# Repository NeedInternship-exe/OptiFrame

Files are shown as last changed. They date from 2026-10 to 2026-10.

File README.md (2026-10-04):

# OptiFrame — des verres recyclés à la monture imprimée en 3D

Web app mobile (défi CodeML × Santé Numérique Sans Frontières) : on photographie un verre de lunettes
recyclé posé sur **une simple feuille blanche** (ou sur notre tapis imprimé, plus précis), l’app mesure son contour au dixième de millimètre et génère une
monture sur mesure **prête à imprimer en 3D**, même quand le verre gauche et le verre droit n’ont pas
la même forme.

**➡️ App : https://needinternship-exe.github.io/OptiFrame/** · aucun compte, aucune installation, fonctionne hors ligne après la 1re ouverture.

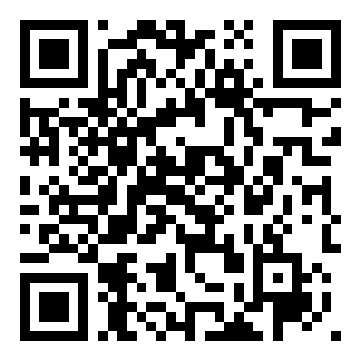
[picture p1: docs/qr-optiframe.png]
QR code de l’application


| Palier | Statut | Où |
|---|---|---|
| 1 · Mesurer (photo → repères → vue de dessus → contour → A, B, périmètre + image de contrôle) | ✅ | onglet **Mesurer** |
| 2 · IA (U-Net entraîné sur données synthétiques, exécuté dans le navigateur) | ✅ | `ml/`, onglet **Pas à pas** |
| 3 · Monture paramétrique (2 contours différents, pont, tenons) + aperçu 3D + STL | ✅ | onglet **Monture** |
| 4 · Valider (superposition contour/rainure, écart entre prises, pied à coulisse) | ✅ | onglet **Valider** |

---

## 1. Tester en 30 secondes

1. Scanner le QR code (Chrome Android ou Safari iOS).
2. Rien sous la main ? **« Essayer avec une photo d’exemple »** lance tout le traitement sur une photo de démonstration (synthétique).
3. **Sans rien imprimer** : une feuille blanche Lettre ou A4 sur une table foncée, les verres dessus, **Photographier** (les 4 coins de la feuille visibles).
4. Plus précis : le tapis imprimé ([Lettre](public/mat/optiframe-mat-lettre.pdf) ou [A4](public/mat/optiframe-mat-A4.pdf)), idéalement posé sur une boîte lumineuse.
5. Onglet **Monture** → **Télécharger monture.stl**. Onglet **Mesurer** → **Contours SVG 1:1** (à imprimer pour poser le verre sur son tracé).

## 2. Dispositif de capture (remontable en moins d’une minute)

**Option 1 : une feuille blanche, rien à imprimer.** Une feuille Lettre ou A4 a une taille connue. Ses 4 coins suffisent pour l’échelle et la perspective (la feuille A4 est citée dans les consignes comme objet de référence).
- Posez la feuille à plat sur une table plus foncée que le papier, puis les verres face bombée vers le haut, à plus de 1 cm des bords. Le verre de gauche est le verre droit (OD).
- L’app trouve la feuille, puis ajuste une droite sur chaque bord, d’abord avec une recherche large qui récupère un coin assombri par une ombre, puis au sous-pixel en pleine résolution.
- Le format (Lettre ou A4) et l’orientation sont choisis automatiquement par **cohérence géométrique** : avec le bon format, l’homographie correspond à une vraie caméra (axes orthogonaux et de même norme).
- Le haut de la photo définit le haut des verres : on tient le téléphone droit.

**Option 2 : le tapis imprimé, plus précis et robuste.**

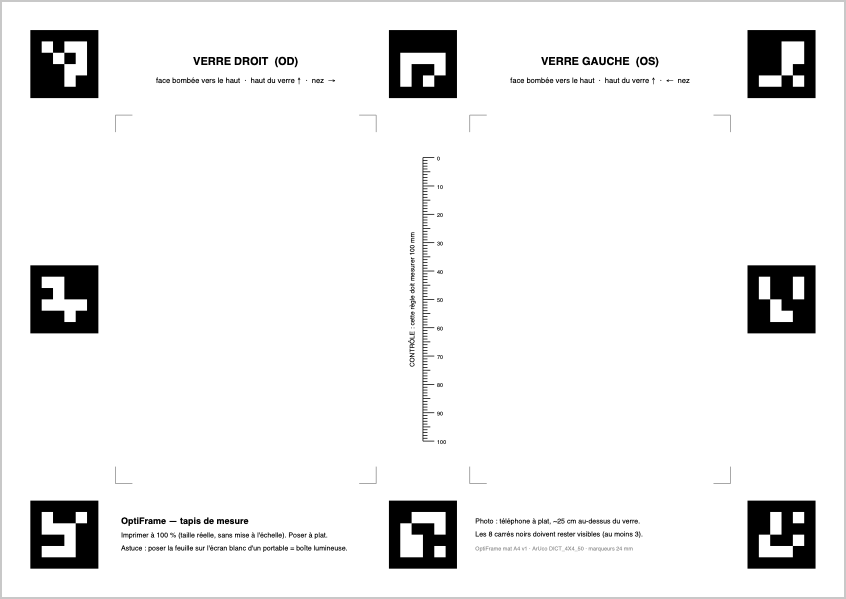
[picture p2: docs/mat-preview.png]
tapis


- **Une feuille imprimée à 100 %**, [Lettre](public/mat/optiframe-mat-lettre.pdf) ou [A4](public/mat/optiframe-mat-A4.pdf). Le même tapis tient sur les deux papiers, car il est dessiné sur leur intersection (279,4 × 210 mm). Il porte 8 marqueurs ArUco (`DICT_4X4_50`, 24 mm) autour de deux zones :
  **OD** (verre droit, à gauche comme sur des lunettes vues de face) et **OS** (verre gauche). Une **règle de 100 mm** permet de vérifier l’échelle d’impression ;
  si l’imprimante a réduit la page, on saisit la longueur réelle dans *Aide → Réglages* et toutes les mesures sont corrigées.
- **Boîte lumineuse (recommandée)** : poser le tapis sur l’écran d’un portable affichant du blanc (bouton *Boîte lumineuse* dans l’app). Le papier devient translucide et le bord du verre ressort en noir très net.
- Au moins 3 repères suffisent : on peut cadrer les deux zones à la fois ou une seule, de plus près.

**Lunettes montées (mode « Lunettes montées »).** Pour mesurer les verres d’une paire complète (par exemple celle du jury) sans les démonter :
- poser les lunettes **face avant contre la feuille**, branches ouvertes vers le haut. Rien ne doit passer devant les verres : une branche repliée sur un verre cache sa forme ;
- l’IA, entraînée aussi sur des montures synthétiques (écaille, couleur, noir, métal fin, acétate transparent), détoure l’**ouverture de chaque cercle**. Le recalage cherche alors le bord « verre clair → cercle sombre » ;
- la photo voit l’arrière : l’app inverse gauche et droite et remet chaque forme en vue de face. Elle corrige la parallaxe pour un bord à environ 3,5 mm du papier (l’épaisseur du cercle), puis ajoute la **profondeur de rainure** (0,5 mm par défaut, réglable), c’est-à-dire la partie du verre cachée dans le cercle.

**Dans les deux cas**, le verre est posé face bombée vers le haut : son bord touche le papier, il est donc dans le plan de référence.
Le bord reste un peu au-dessus du papier : l’app corrige cette **parallaxe** à partir de la position de la caméra retrouvée par l’homographie.

## 3. Comment ça marche

Tout le traitement tourne **dans le navigateur** (Web Workers, WebAssembly) : pas de serveur, les photos ne quittent pas le téléphone.

```
photo ─► 1. Référence ──► 2. Homographie ─► 3. Vue de dessus ─► 4. Segmentation IA ─► 5. Contour sub-pixel ─► mesures
          ArUco (tapis)       mm ↔ px            6 px/mm (contrôle)   U-Net, ONNX Runtime    recalage sur la photo     A, B, périmètre,
          ou 4 coins de       (32 ou 4 coins)    3 px/mm (IA)         Web (wasm)             d'origine + parallaxe     ED, SVG 1:1
          la feuille
                                                                                                    │
                                                    monture.stl ◄─ 6. CAO paramétrique (manifold-3d) ◄┘
```

1. **Référence** — sans tapis, la feuille blanche est détectée et ses bords ajustés (voir plus haut). Avec le tapis, OpenCV.js détecte les marqueurs sur une copie réduite (rapide), puis chaque coin est **ré-estimé en pleine résolution
   en ajustant une droite sur les 4 bords de chaque marqueur** (~30 profils de gradient sub-pixel par bord, rejet des aberrants), puis intersection.
   Utiliser des bords entiers plutôt que des pixels de coin rend l’homographie bien plus stable. La largeur de transition des bords donne une **mesure de netteté en mm**.
2. **Homographie** — jusqu’à 32 correspondances mm ↔ px, RANSAC puis moindres carrés. Indicateurs affichés : erreur de reprojection (typiquement < 0,02 mm), résolution (px/mm), inclinaison et hauteur de la caméra.
3. **Redressement** — chaque zone visible est ré-échantillonnée en vue de dessus (anti-crénelage par réduction préalable), à 6 px/mm pour l’image de contrôle et 3 px/mm pour l’IA.
4. **Segmentation** — un U-Net (0,5 M paramètres) donne une carte de probabilité « verre ». Repli automatique sur une segmentation classique (normalisation de l’éclairage + Canny + remplissage) si le modèle n’est pas chargé.
5. **Contour** — iso-ligne 0,5 sub-pixel de la carte, puis **recalage sur le bord réel dans la photo d’origine** : chaque point est déplacé le long de sa normale vers le pic de gradient « bord sombre → papier », échantillonné directement dans la photo pleine résolution via l’homographie (aucune perte de ré-échantillonnage). Filtre médian + lissage de Fourier (60 harmoniques), puis correction de parallaxe, d’échelle d’impression et d’un biais calibrable.
6. **Mesures (système boxing, ISO 8624)** — A, B, périmètre, diamètre effectif. Un verre posé de travers est redressé (rectangle d’encadrement minimal, ±8°).

## 4. Données et IA

> Détails, commandes et courbes : [`ml/README.md`](ml/README.md).

**Le problème** : un verre est transparent ; reflets, ombres, traitements anti-reflet colorés et bords peu contrastés font échouer le seuillage classique.
Aucun jeu de données n’existe pour « un verre de lunettes posé sur un tapis vu de dessus ». **Nous l’avons fabriqué.**

**Idée clé : entraîner dans le domaine redressé.** L’app redresse toujours la zone du tapis en vue de dessus à 3 px/mm avant la segmentation.
Le modèle ne voit donc jamais de perspective ni d’échelle variable : seulement du papier, les marques imprimées du tapis et un verre.
Ce domaine très contraint est **simulable de façon réaliste** — chaque image d’entraînement est rendue à partir du vrai fichier du tapis.

**Générateur synthétique** ([`ml/lenssynth.py`](ml/lenssynth.py), [`ml/dataset.py`](ml/dataset.py)) — chaque échantillon est entièrement déterminé par sa graine (jeu reproductible, illimité, 60 ms/image) :
- **formes** : superellipses, séries de Fourier, aviateur, œil-de-chat, pantos, rond, hexagonal/octogonal (A de 33 à 64 mm) ;
- **optique** : réfraction (minification/grossissement du papier et des marques), transmission et teintes (verres clairs, anti-reflet, solaires) ;
- **le bord vu de dessus** : bande sombre de largeur et contraste variables, reflets brillants, **segments où le bord disparaît presque** ;
- **pièges** : « anneau myopique » à l’intérieur des verres épais, ombre décalée du bord, ombre du téléphone, reflets de fenêtre et du téléphone, voiles colorés d’anti-reflet, points d’encre du frontofocomètre, trous de perçage, poussières ;
- **éclairage et caméra** : mode boîte lumineuse / lumière ambiante, gradients, flou, bruit, gamma, balance des blancs, JPEG.

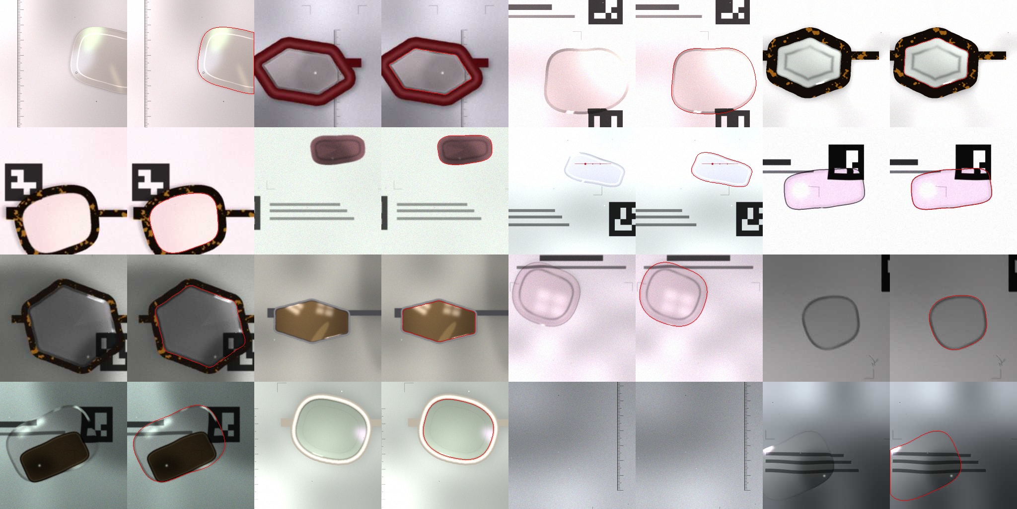
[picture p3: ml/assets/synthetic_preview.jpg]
échantillons synthétiques


**Modèle** ([`ml/train.py`](ml/train.py)) — U-Net à convolutions 3×3 (12→96 canaux, 5 niveaux), 516 k paramètres, ~2 GMAC par zone, entièrement convolutif.
Perte : entropie croisée pondérée ×5 près du bord + Dice, étiquettes douces anti-crénelées (le bord à 0,5 tombe exactement sur le vrai contour).
AdamW + OneCycle, 6 000 itérations puis 5 000 de reprise à taux décroissant × 16 images (176 000 images vues), IoU de validation 0,968, GPU Apple M4 (MPS), ~2 h. Export ONNX (2 Mo), exécution par ONNX Runtime Web (wasm SIMD) : ~0,3 s par zone sur un M4.

**Évaluation de bout en bout** ([`bench/run.ts`](bench/run.ts)) — le *même code TypeScript que l’app* est exécuté sous Node sur 24 photos de téléphone simulées
([`ml/make_photos.py`](ml/make_photos.py) : 36 verres, inclinaison 0–28°, téléphone tourné, table autour du tapis, défocalisation, bruit, JPEG), dont le contour exact est connu (tapis : 24 photos, 34 verres ; feuille blanche : 24 photos, 35 verres) :

| Référence · méthode | Verres trouvés | Erreur moy. A et B | ≤ 1 mm | lumière ambiante | boîte lumineuse |
|---|---|---|---|---|---|
| Tapis · classique (sans IA) | 29 / 34 | 1,86 mm | 68 % | 2,24 mm | 0,06 mm |
| Tapis · IA sans affinage | 34 / 34 | 0,21 mm | 100 % | 0,21 mm | 0,22 mm |
| **Tapis · IA + affinage** | **34 / 34** | **0,16 mm** | **100 %** | 0,19 mm | 0,07 mm |
| **Feuille Lettre · IA + affinage** | **23 / 23** | **0,17 mm** | 96 % | 0,17 mm | — |
| **Feuille A4 · IA + affinage** | 11 / 12 | **0,16 mm** | 92 % | 0,16 mm | — |

Résolution caméra navigateur (1920 × 1440, tapis) : 0,29 mm, 93 % ≤ 1 mm. Photos de test reproductibles : `python make_photos.py [--sheet letter|a4] [--res 1920x1440]`.

**Vérité terrain réelle** : protocole pour vos propres verres — saisir les cotes au pied à coulisse (système boxing) dans *Valider*, l’app calcule l’erreur, exporte un CSV et peut **calibrer automatiquement le biais du contour** (*Aide → Calibrer*).

**Sources et licences** : aucune donnée personnelle, aucune image tierce — 100 % des images d’entraînement sont générées par nos scripts (licence MIT du dépôt).
Pas de modèle pré-entraîné (Segment Anything a été envisagé, mais ses ~40 Mo et plusieurs secondes par image sur téléphone ne tiennent pas le budget de 30 s et le mode hors ligne).

## 5. La monture

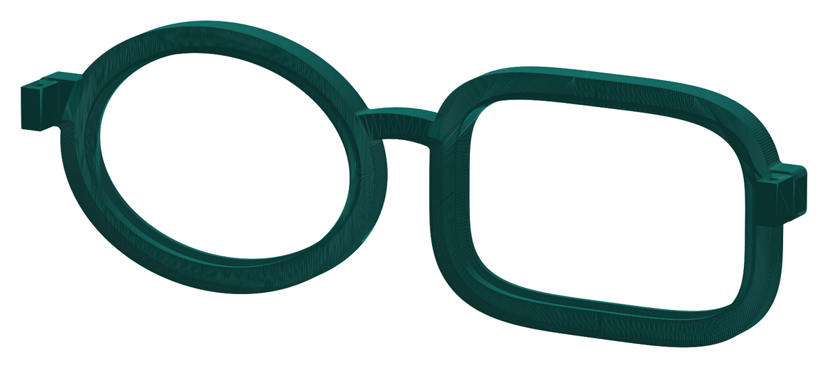
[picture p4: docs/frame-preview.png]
monture


Générée par [`src/frame/frame.ts`](src/frame/frame.ts) avec **manifold-3d**, une bibliothèque qui garantit un maillage fermé (STL valide). Le module est vérifié par un test automatique : `npm run test`.

- **Chaque cercle épouse son verre** : le contour mesuré est décalé vers l’extérieur (largeur du cercle, 4 mm par défaut). Les deux verres peuvent avoir des formes différentes. S’il en manque un, l’autre est utilisé en miroir.
- **Rainure en V à 45°** pour le clipsage, avec un jeu de 0,2 mm au fond (réglable de 0 à 0,5 mm). Une lèvre avant de 0,8 mm retient le verre et une lèvre arrière de 0,4 mm le clipse. Les parois à 45° **s’impriment sans supports**, face avant sur le plateau.
- **Pont** en arche réglable (18 mm par défaut, norme DBL), avec les centres de boxing alignés sur la ligne de référence.
- **Tenons des branches** avec un bloc de charnière. Le trou de l’axe est **en goutte d’eau** pour s’imprimer sans support ; un morceau de filament de 1,75 mm sert d’axe.
- **Contrôles sur le maillage final** : arêtes libres, genre topologique, volume, masse. L’app découpe la monture générée au niveau de la rainure et mesure l’écart réel avec le contour du verre (onglet Valider). Valeur obtenue : 0,200 mm pour une consigne de 0,2.

## 6. Exigences du format

| Exigence | Réalisation |
|---|---|
| HTTPS + QR code | GitHub Pages ([workflow](.github/workflows/deploy.yml)) ; QR code dans l’app (*Aide*) et ci-dessus |
| Aucune installation, compte ou clé | Site statique, PWA installable en option |
| Mobile d’abord, utilisable à une main | Barre d’onglets en bas, gros boutons, testé à 375 px de large |
| Caméra intégrée + import en repli | `getUserMedia` avec guidage en direct (repères détectés, zone visible, inclinaison), `ImageCapture.takePhoto()` en pleine résolution sur Android, sinon import de fichier |
| Traitement dans le navigateur | OpenCV.js + ONNX Runtime Web dans un Worker, CAO dans un second Worker, cache hors ligne (service worker) |
| Moins de 30 s par paire | ~1,6 à 2 s pour une photo de la paire sur un M4 |
| Export du contour en SVG 1:1 | `contours-1-1.svg` (A4, règle de contrôle de 50 mm) |
| Messages clairs | Tapis absent, repères insuffisants, photo floue, feuille non plane, photo trop inclinée, zone hors cadre, verre absent, verre au bord, contour incertain : chaque message est accompagné d’un conseil |

## 7. Limites connues (honnêtement)

- **Modèle entraîné uniquement sur des images synthétiques.** Les photos réelles peuvent présenter des effets non simulés. Le banc d’essai mesure la précision sur des photos synthétiques : il faut **valider sur de vrais verres au pied à coulisse** (protocole intégré à l’app) et compléter avec des photos réelles annotées (voir `ml/README.md`, « capture appariée »).
- **L’échelle dépend de la référence.** Avec le tapis, contrôler la règle de 100 mm (correction possible dans l’app). Avec une feuille blanche, la précision dépend de la coupe du papier (±0,5 mm sur 280 mm, soit environ 0,1 mm sur un verre) et de sa planéité. La feuille doit contraster avec la table.
- **Hauteur du bord pour la parallaxe** : la valeur par défaut est de 1 mm. Une erreur de 1 mm sur cette hauteur produit environ 0,1 à 0,2 mm d’erreur sur A.
- **Orientation du verre** : A et B dépendent de l’orientation horizontale du verre. Il faut poser le verre droit ; l’app ne corrige que ±8°.
- **Lunettes montées** : le contour d’un verre monté est estimé à partir de l’ouverture du cercle plus une profondeur de rainure typique (0,5 mm). C’est moins précis qu’un verre démonté, car la profondeur réelle varie de 0,3 à 1 mm selon la monture. La paire doit être posée face avant contre la feuille, branches ouvertes.
- **Monture** : les branches ne sont pas générées, seulement les tenons. Le clipsage dépend du matériau : en PLA rigide, réduire la lèvre arrière ou passer en PETG.
- **Sans IA** (modèle non chargé), la segmentation classique n’est fiable qu’avec la boîte lumineuse.

## 8. Lancer en local

```bash
npm install
npm run dev          # http://localhost:5173 (caméra : utiliser l'import de fichier, ou HTTPS)
npm run test         # génère une monture test et vérifie maillage fermé + rainure
npm run bench        # précision de bout en bout sur bench/photos (après ml/make_photos.py)
npm run build        # site statique dans dist/
```

Partie IA (Python 3.11+) :

```bash
cd ml && python -m venv .venv && .venv/bin/pip install -r requirements.txt
.venv/bin/python gen_mat.py                 # tapis PDF/SVG + rendus raster
.venv/bin/python dataset.py 16              # aperçu des données synthétiques
.venv/bin/python train.py --out runs/v1     # entraînement (MPS / CUDA / CPU)
.venv/bin/python export_onnx.py runs/v1/best.pt ../public/models/lens_seg.onnx
.venv/bin/python make_photos.py --n 24 --out ../bench/photos
```

## 9. Structure

```
src/core/      géométrie, homographie et pose caméra, mesures boxing, fusion de prises
src/vision/    pipeline (ArUco, redressement, segmentation, contour, affinage), worker, messages
src/frame/     CAO de la monture (manifold-3d), export STL, worker
src/ui/        interface Preact (caméra, onglets), dessins de contrôle
src/export/    SVG 1:1
ml/            tapis, générateur synthétique, entraînement, export ONNX, photos de test
bench/         banc d'essai de bout en bout (Node) et test de la monture
shared/        géométrie du tapis (partagée par Python et TypeScript)
```

## 10. Licences et outils

- Code du projet : **MIT**. Données d’entraînement : générées par nos scripts (MIT).
- [OpenCV.js](https://opencv.org) 4.9 (Apache 2.0) · [ONNX Runtime Web](https://onnxruntime.ai) (MIT) · [manifold-3d](https://github.com/elalish/manifold) (Apache 2.0) · [three.js](https://threejs.org) (MIT) · [Preact](https://preactjs.com) (MIT) · [qrcode](https://github.com/soldair/node-qrcode) (MIT) · [Vite](https://vite.dev) + vite-plugin-pwa (MIT).
- Entraînement : [PyTorch](https://pytorch.org) (BSD-3), opencv-python (Apache 2.0 / MIT), NumPy (BSD), ReportLab (BSD) pour le PDF du tapis.
- **Outils d’IA utilisés** : Claude Code (Anthropic, modèle Claude Opus) comme assistant de programmation pour l’architecture, le code, le générateur de données et la rédaction. Toutes les mesures citées proviennent des scripts du dépôt et sont reproductibles.

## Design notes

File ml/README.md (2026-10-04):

# Dossier « données et IA »

Objectif : isoler un verre de lunettes **transparent** dans une photo de téléphone, de façon assez fiable pour mesurer
sa largeur A et sa hauteur B à moins de 1 mm, malgré les reflets, les ombres et un bord souvent à peine visible.

## 1. Pourquoi des données synthétiques ?

Aucun jeu public ne montre « un verre de lunettes démonté, posé à plat, vu de dessus ». Les jeux d’objets transparents
(Trans10K, ClearGrasp…) montrent des verres à boire et des bouteilles, en perspective, avec des licences souvent non commerciales.
Ils ne correspondent ni au domaine ni à la précision voulue (sub-millimétrique).

**Le domaine redressé.** L’app commence par repérer les marqueurs ArUco du tapis, puis redresse chaque zone en vue de
dessus à 3 px/mm. Le réseau ne voit donc jamais de perspective ni d’échelle variable : seulement le papier, les marques
imprimées du tapis (coins, règle, textes, bords de marqueurs) et un verre. On peut simuler ce domaine très fidèlement, car on
part du **fichier exact du tapis** ([`gen_mat.py`](gen_mat.py) produit à la fois le PDF imprimé et les rendus utilisés pour l’entraînement).

## 2. Le générateur ([`lenssynth.py`](lenssynth.py), [`dataset.py`](dataset.py))

Chaque échantillon 256 × 256 px (85 × 85 mm) est rendu à 6 px/mm puis réduit à 3 px/mm (étiquettes douces anti-crénelées).
**Une graine entière détermine entièrement une image** : le jeu est illimité, reproductible, et ne contient aucune donnée personnelle.

| Famille | Ce qui est simulé (tirages aléatoires) |
|---|---|
| Formes | superellipse (p 2–5,5), Fourier, aviateur, œil-de-chat, pantos, rond, hexagone/octogone arrondi ; A 33–64 mm, B/A 0,48–1 ; rotation ±25°, miroir |
| Papier et lumière | teinte du papier, encre 4–25 % de gris, gradients et champ d’éclairage, vignettage, texture du papier, **ombre du téléphone** (35 %), **mode boîte lumineuse** (35 %) |
| Optique du verre | réfraction (grandissement 0,82–1,18 et distorsion lisse), transmission 85–99,5 %, **verres solaires teintés** (10 %) |
| Bord vu de dessus | bande sombre de 0,25 à 2,6 mm, contraste variable le long du contour, profils uniforme, dégradé ou ligne ; **segments où le bord disparaît** (30 %) ; liseré brillant interne ; reflets ponctuels |
| Pièges | **anneau myopique** interne (35 %), **ombre décalée du bord** (40 % en lumière ambiante), reflets en taches, de fenêtre ou du téléphone (sombre avec un point brillant), voile coloré d’anti-reflet (vert, violet, bleu, or), points et traits d’encre du frontofocomètre (25 %), trous de perçage (6 %), poussières, cheveux |
| Composition | 1 verre (86 %), 2 verres dont un partiellement hors champ (8 %), aucun verre (6 %, apprend à ne rien détecter) ; erreur d’échelle résiduelle ±6 % |
| Caméra | flou gaussien et de bougé, bruit dépendant du signal, gamma 0,8–1,25, balance des blancs, JPEG q45–95 |

aperçu

*Aperçu (`python dataset.py 16`) : image rendue à gauche, contour de vérité terrain en rouge à droite.*

## 3. Le modèle ([`train.py`](train.py))

- **U-Net à convolutions 3×3** : canaux 12, 24, 32, 48, 64, 96, 5 sous-échantillonnages, décodeur avec connexions de saut et suréchantillonnage bilinéaire, 516 k paramètres, ~2 GMAC pour une zone de 416 × 288 px.
- **Pourquoi des convolutions classiques et pas « depthwise »** : une première version MobileNet-like (280 k paramètres) prenait 557 ms par itération sur le GPU Apple (MPS), contre 225 ms pour cette version. ONNX Runtime Web exécute aussi très bien les convolutions denses en wasm SIMD.
- **Entièrement convolutif** : entraîné sur des recadrages 256 × 256, appliqué tel quel à une zone complète de 96 × 134 mm.
- La normalisation est intégrée au graphe : l’app envoie du RGB dans [0, 1].

**Entraînement** : perte = entropie croisée pondérée ×5 à moins de 1,5 mm du bord + 0,5 × Dice. AdamW (lr 2e-3, wd 1e-4), OneCycle,
6 000 itérations puis reprise de 5 000 itérations (lr 1e-3 décroissant) × 16 images, flux infini, validation sur 512 images fixes (graines 10 000 000+).
Matériel : Apple M4 (MPS), environ 2 h. Données générées en parallèle par 9 processus.

**Export** ([`export_onnx.py`](export_onnx.py)) : ONNX opset 17, hauteur et largeur dynamiques, 2 Mo. Écart maximal PyTorch ↔ onnxruntime : 7·10⁻⁶.
**Inférence** : ONNX Runtime Web (wasm), ~0,25 à 0,3 s par zone sur un M4 (mono-fil). Le modèle et le moteur sont mis en cache pour le mode hors ligne.

## 4. IA + géométrie : le contour final

Le réseau donne une carte de probabilité robuste mais à 0,33 mm/px. Pour atteindre la précision visée :
1. **iso-ligne 0,5 sub-pixel** de la carte : les étiquettes douces placent le 0,5 sur le vrai bord ;
2. **recalage sur la photo d’origine** : le long de chaque normale, on échantillonne la photo pleine résolution (via l’homographie, sans ré-échantillonnage) et on se cale sur le pic de gradient « bord sombre → papier » le plus proche (pondération gaussienne de 0,45 mm autour du contour IA, filtre médian, lissage) ;
3. corrections physiques : parallaxe du bord (hauteur caméra estimée), échelle d’impression, biais calibré.

L’IA apporte la **robustesse** (savoir où est le verre malgré les pièges), la géométrie apporte la **précision** (sub-pixel sur l’image native).

## 5. Évaluation

**Validation segmentation** (512 images synthétiques) : voir `runs/v1/log.json` (IoU, erreur A/B au pixel près).

**Bout en bout** ([`../bench/run.ts`](../bench/run.ts)) : le code TypeScript de l’app est exécuté sous Node sur 24 photos de téléphone
simulées ([`make_photos.py`](make_photos.py)). Ces photos comptent 36 verres, des inclinaisons de 0 à 28°, un téléphone tourné, la table
visible autour du tapis, de la défocalisation, du bruit et de la compression JPEG. A et B sont mesurés par la même procédure sur le contour trouvé et sur le contour vrai.

| Référence · méthode | Verres trouvés | Erreur moy. A et B | ≤ 1 mm | lumière ambiante | boîte lumineuse |
|---|---|---|---|---|---|
| Tapis · classique (sans IA) | 29 / 34 | 1,86 mm | 68 % | 2,24 mm | 0,06 mm |
| Tapis · IA sans affinage | 34 / 34 | 0,21 mm | 100 % | 0,21 mm | 0,22 mm |
| **Tapis · IA + affinage** | **34 / 34** | **0,16 mm** | **100 %** | 0,19 mm | 0,07 mm |
| **Feuille Lettre · IA + affinage** | **23 / 23** | **0,17 mm** | 96 % | 0,17 mm | — |
| **Feuille A4 · IA + affinage** | 11 / 12 | **0,16 mm** | 92 % | 0,16 mm | — |

Résolution caméra navigateur (1920 × 1440, tapis) : 0,29 mm, 93 % ≤ 1 mm. Photos de test reproductibles : `python make_photos.py [--sheet letter|a4] [--res 1920x1440]`.

## 6. Passer aux vraies photos : la « capture appariée »

La limite principale est l’écart entre synthétique et réel. Pour annoter de vraies photos difficiles **sans annotation manuelle** :
1. poser un verre sur le tapis, sur la **boîte lumineuse** : le bord est noir et net, la segmentation (même classique) est quasi parfaite ;
2. **sans bouger le verre**, éteindre l’écran et reprendre des photos en lumière de la pièce, avec reflets, sous un autre angle ;
3. comme toutes les photos sont redressées dans les coordonnées du tapis (en mm), **le masque de la photo facile s’applique exactement aux photos difficiles**.

On obtient en quelques minutes des dizaines d’exemples réels annotés, prêts pour affiner le modèle (`train.py --resume runs/v1/best.pt`, avec un mélange d’images réelles et synthétiques).
Les photos de l’évaluation finale ne sont jamais utilisées pour l’entraînement.

## 7. Licences

- Images d’entraînement : 100 % générées par nos scripts (MIT). Aucune image de visage, de nom ni d’ordonnance.
- Pas de poids pré-entraînés : le modèle est entraîné de zéro.
- Outils : PyTorch (BSD-3), OpenCV (Apache 2.0), NumPy (BSD), ONNX / onnxruntime (Apache 2.0 / MIT), ReportLab (BSD), Matplotlib (PSF).

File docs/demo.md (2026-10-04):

# Démo OptiFrame : 5 minutes + 2 minutes de questions

## Matériel (à vérifier avant de passer)
- 2 tapis A4 imprimés à 100 % : contrôler la règle de 100 mm au réglet, garder un tapis de rechange.
- Un portable ou une tablette avec l’app ouverte en mode **Boîte lumineuse** (Aide → Boîte lumineuse), luminosité au maximum.
- Un téléphone chargé avec l’app déjà ouverte une fois : le moteur est en cache, ce qui permet de fonctionner sans réseau.
- Le QR code affiché (README ou Aide → Partager), une monture imprimée si possible, la vidéo de secours sur le téléphone.

## Déroulé

| Temps | Action | Ce qu’on dit |
|---|---|---|
| 0:00 | QR code à l’écran, le jury scanne | « Aucune installation, aucun compte. Tout tourne dans le navigateur, hors ligne : pensé pour les zones sans opticien. » |
| 0:30 | Poser le tapis sur la boîte lumineuse, les 2 verres du jury face bombée vers le haut | « Dispositif en 30 secondes : une feuille A4, 8 repères ArUco, et l’écran d’un portable comme boîte lumineuse. » |
| 1:00 | **Photographier** : le guidage passe au vert (« Prêt · 8 repères ») | « Une seule photo pour les deux verres. » |
| 1:20 | Résultat : image de contrôle, A, B, périmètre | Lire A et B à voix haute, le jury compare avec son pied à coulisse. |
| 1:50 | **Pas à pas** : repères → vue redressée → carte de l’IA → contour affiné | « Affinage sub-pixel des repères, homographie à 0,01 mm de reprojection. L’IA trouve le verre malgré les reflets, puis on recale le contour sur la photo d’origine en pleine résolution. » |
| 2:40 | **Monture** : aperçu 3D, régler le pont (18 mm), **Télécharger monture.stl** | « Deux verres de formes différentes, deux cercles différents. Rainure en V à 45° qui s’imprime sans supports, jeu de 0,2 mm, tenons avec charnière. » |
| 3:30 | **Valider** : superposition verre/rainure (0,20 mm mesuré sur le maillage), reprendre une photo pour montrer ΔA/ΔB | « On contrôle la cohérence sur le maillage réel et entre deux prises. » |
| 4:10 | Données et IA (README) | « Aucun jeu de données n’existait : générateur synthétique dans le domaine redressé, 176 000 images. Sur photos simulées, l’erreur passe de 1,9 mm à 0,16 mm avec l’IA. Et la *capture appariée* permet d’annoter automatiquement de vraies photos. » |
| 4:40 | Limites (honnêtement) | « Modèle entraîné sur du synthétique, validé sur nos verres au pied à coulisse ; verres démontés uniquement ; les branches ne sont pas générées. » |

## Questions probables
- **Pourquoi pas Segment Anything ?** ~40 Mo et plusieurs secondes par image sur téléphone, sans mode hors ligne. Notre U-Net pèse 2 Mo et passe en environ 0,3 s.
- **D’où vient la précision ?** Repères affinés sur leurs bords, homographie sur 32 coins, contour recalé sur la photo native, correction de parallaxe, échelle d’impression contrôlée.
- **Et si l’imprimante réduit la page ?** On mesure la règle de 100 mm et on saisit la valeur : toutes les mesures sont corrigées, même les anciennes.
- **Le verre se clipse-t-il ?** Lèvre avant de 0,8 mm, lèvre arrière de 0,4 mm, jeu de 0,2 mm, tout est réglable. En PLA, on peut chauffer légèrement ; le PETG est plus souple.

## Plan B
- Pas de réseau : l’app est en cache (l’ouvrir une fois avant).
- Caméra refusée : bouton **Importer** (photo prise avec l’appareil photo natif).
- Rien ne marche : **Essayer avec une photo d’exemple**, puis la vidéo de secours.

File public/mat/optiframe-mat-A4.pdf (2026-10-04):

## VERRE DROIT (OD)

face bombée vers le haut · haut du verre ↑ · nez →

## VERRE GAUCHE (OS)

face bombée vers le haut · haut du verre ↑ · ← nez

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
CONTRÔLE : cette règle doit mesurer 100 mm

## OptiFrame — tapis de mesure

Imprimer à 100 % (taille réelle, sans mise à l'échelle). Poser à plat. Astuce : poser la feuille sur l'écran blanc d'un portable = boîte lumineuse.

Photo : téléphone à plat, ~25 cm au-dessus du verre. Les 8 carrés noirs doivent rester visibles (au moins 3).

OptiFrame mat v2 (Lettre/A4) · ArUco DICT_4X4_50 · marqueurs 24 mm

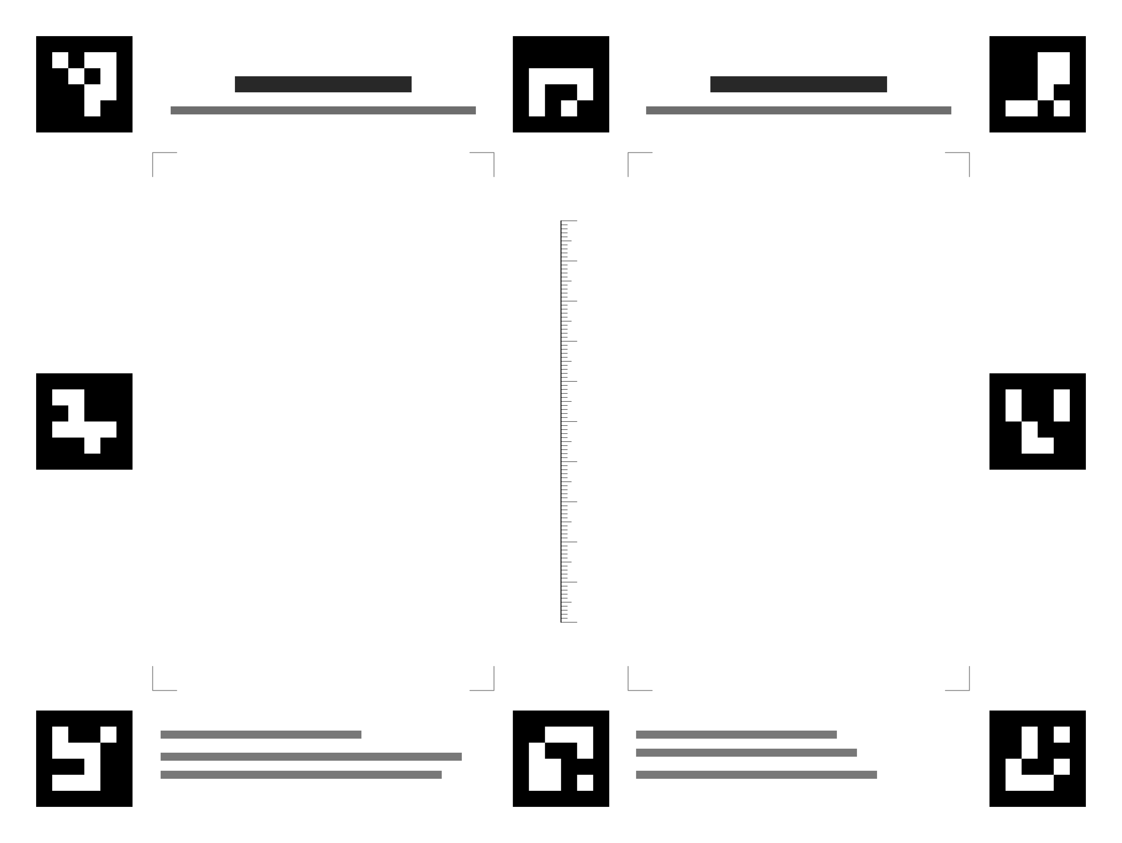
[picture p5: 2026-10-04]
ml/assets/mat_12ppm.png

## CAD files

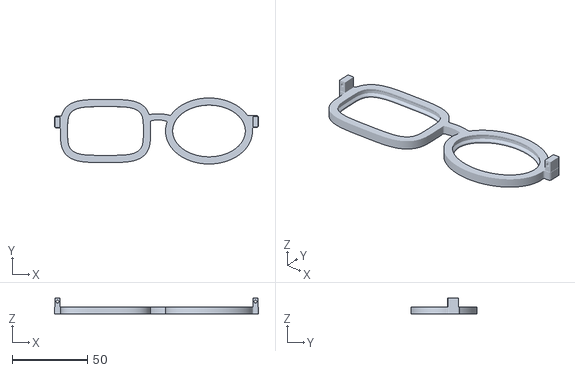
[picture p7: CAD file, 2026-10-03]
bench/out/monture-test.stl
136.0 x 44.0 x 10.6

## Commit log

2026-10-03 Frame generator (V-groove, bridge, hinges), UI measure/frame tabs, SVG export, early AI model
    [monture-test.stl]
2026-10-03 Complete mobile UI (camera, frame, validation, step-by-step, help), PWA offline caching, GitHub Pages workflow
2026-10-04 Blank-sheet mode (Letter/A4, no printing), one photo per lens, Letter-compatible printed mat, sheet benchmark
2026-10-04 Reject impossible lens shapes (size, irregular outline) instead of saving them
2026-10-04 Mounted-glasses mode: frame-aware model (synthetic frames), back-view mirroring, groove depth, glasses benchmark
